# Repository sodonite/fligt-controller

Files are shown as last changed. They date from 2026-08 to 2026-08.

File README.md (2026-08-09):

Flight Controller
This is a custom flight controller engineered specifically for rocket stabilization and control. Powered by an STM32F722 microcontroller, it incorporates an ICM-45686 IMU alongside a BMP580 barometer, with an integrated microSD card slot dedicated to flight telemetry logging. The board supports 2S LiPo battery configurations featuring onboard charging functionality, as well as dedicated PWM output channels for servo actuation.

Designed in KiCad, the entire project is completely open source.

PCB:

3D Image:


Schematic:


Technical Specifications
Brain: STM32F722RET6 microcontroller.
IMU: ICM-45686 high-precision motion sensor.
Barometer: BMP580 altitude tracker.
Actuation: Multi-channel servo output via PWM.
Data Logging: Onboard MicroSD card slot.
Power Management:
BQ25883: 2-cell LiPo battery charger via USB-C.
TPS63070: 5V Buck-Boost regulator for servos.
LMR51430: 3.3V Buck regulator for the MCU and sensors.
D2: RGB LED (Common Anode) — Visual status indicator for system initialization, ready-to-fly state, and critical error reporting (IMU, battery, SD card, and power rails).

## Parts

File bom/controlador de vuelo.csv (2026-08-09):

Id | Identificador | Huella | Cantidad | Identificación | Suministrador y ref
1 | C1, C28, C29, C30 | C_0402_1005Metric | 4 | 1uF
2 | C2, C9, C12 | C_0603_1608Metric | 3 | 10uF
3 | C3, C5, C31 | C_0402_1005Metric | 3 | 10uF
4 | C4 | C_0201_0603Metric | 1 | 47nF
5 | C6 | C_0603_1608Metric | 1 | 44uF
6 | C7, C8 | C_0805_2012Metric | 2 | 10uF
7 | C10, C11, C13 | C_0805_2012Metric | 3 | 22uF
8 | C14, C15, C19, C20, C21, C22, C23, C24, C25, C26, C27, C37 | C_0201_0603Metric | 12 | 100nF
9 | C16 | C_0603_1608Metric | 1 | 2.2uF
10 | C17, C18 | C_0402_1005Metric | 2 | 22uF
11 | C32 | C_0201_0603Metric | 1 | 2.2uF
12 | C33, C34 | C_0201_0603Metric | 2 | 20pF
13 | C35, C36 | C_0201_0603Metric | 2 | 6.8pF
14 | Card1 | TF-SMD_TF-01A | 1 | TF-01A
15 | D1 | LED_0402_1005Metric | 1 | LED
16 | J1 | TerminalBlock_Xinya_XY308-2.54-2P_1x02_P2.54mm_Horizontal | 1 | Screw_Terminal_01x02
17 | J2, J3 | PinHeader_1x03_P2.54mm_Vertical | 2 | Conn_01x03
18 | L4 | L0603 | 1 | FCM1608KF-601T03
19 | L5 | L2520 | 1 | DFE252012F-1R0M=P2
20 | L6 | IND-SMD_L4.0-W4.0-A | 1 | XFL4020-152MEC
21 | L7 | IND-SMD_L3.0-W3.0 | 1 | YHNR3015-5R6M
22 | LED1 | LED-SMD_4P-L1.6-W1.5-TR-1 | 1 | SZYY1615RGB-B 4PIN
23 | R1, R2 | R_0201_0603Metric | 2 | 5.1k
24 | R3 | R_0201_0603Metric | 1 | 383
25 | R4 | R_0201_0603Metric | 1 | 5.23K
26 | R5 | R_0201_0603Metric | 1 | 30.1K
27 | R6, R7, R8, R9, R10, R11, R12, R13, R16, R17, R18, R19, R20, R21, R22 | R_0201_0603Metric | 15 | 10K
28 | R14 | R_0402_1005Metric | 1 | 100K
29 | R15 | R_0402_1005Metric | 1 | 22.1K
30 | R23 | R_0201_0603Metric | 1 | 330
31 | R24, R25 | R_0201_0603Metric | 2 | 220
32 | SW1, SW2 | SW-SMD_L3.9-W3.0-P4.45 | 2 | TS-1088-AR02016
33 | U1 | VFQFPN-24_L4.0-W4.0-P0.50-BL-EP2.8 | 1 | BQ25883RGER
34 | U3 | LQFP-64_10x10mm_P0.5mm | 1 | STM32F722RETx
35 | U5 | VQFN-HR-15_L3.0-W2.5-P0.50-BL_TPS63070RNMR | 1 | TPS63070RNMR
36 | U6 | SOT-23-6 | 1 | LMR51430
37 | U7 | LGA-14_L3.0-W2.5-P0.50-TL | 1 | ICM-45686
38 | U8 | LGA-10_L2.0-W2.0-P0.50-TL_BMP580 | 1 | BMP580
39 | USB1 | USB-C-SMD_TYPE-C-16PIN-2MD-073 | 1 | TYPE-C 16PIN 2MD
40 | X1 | CRYSTAL-SMD_4P-L3.2-W2.5-BL | 1 | X322525MOB4SI
41 | X2 | FC-135R_L3.2-W1.5 | 1 | Q13FC1350000400

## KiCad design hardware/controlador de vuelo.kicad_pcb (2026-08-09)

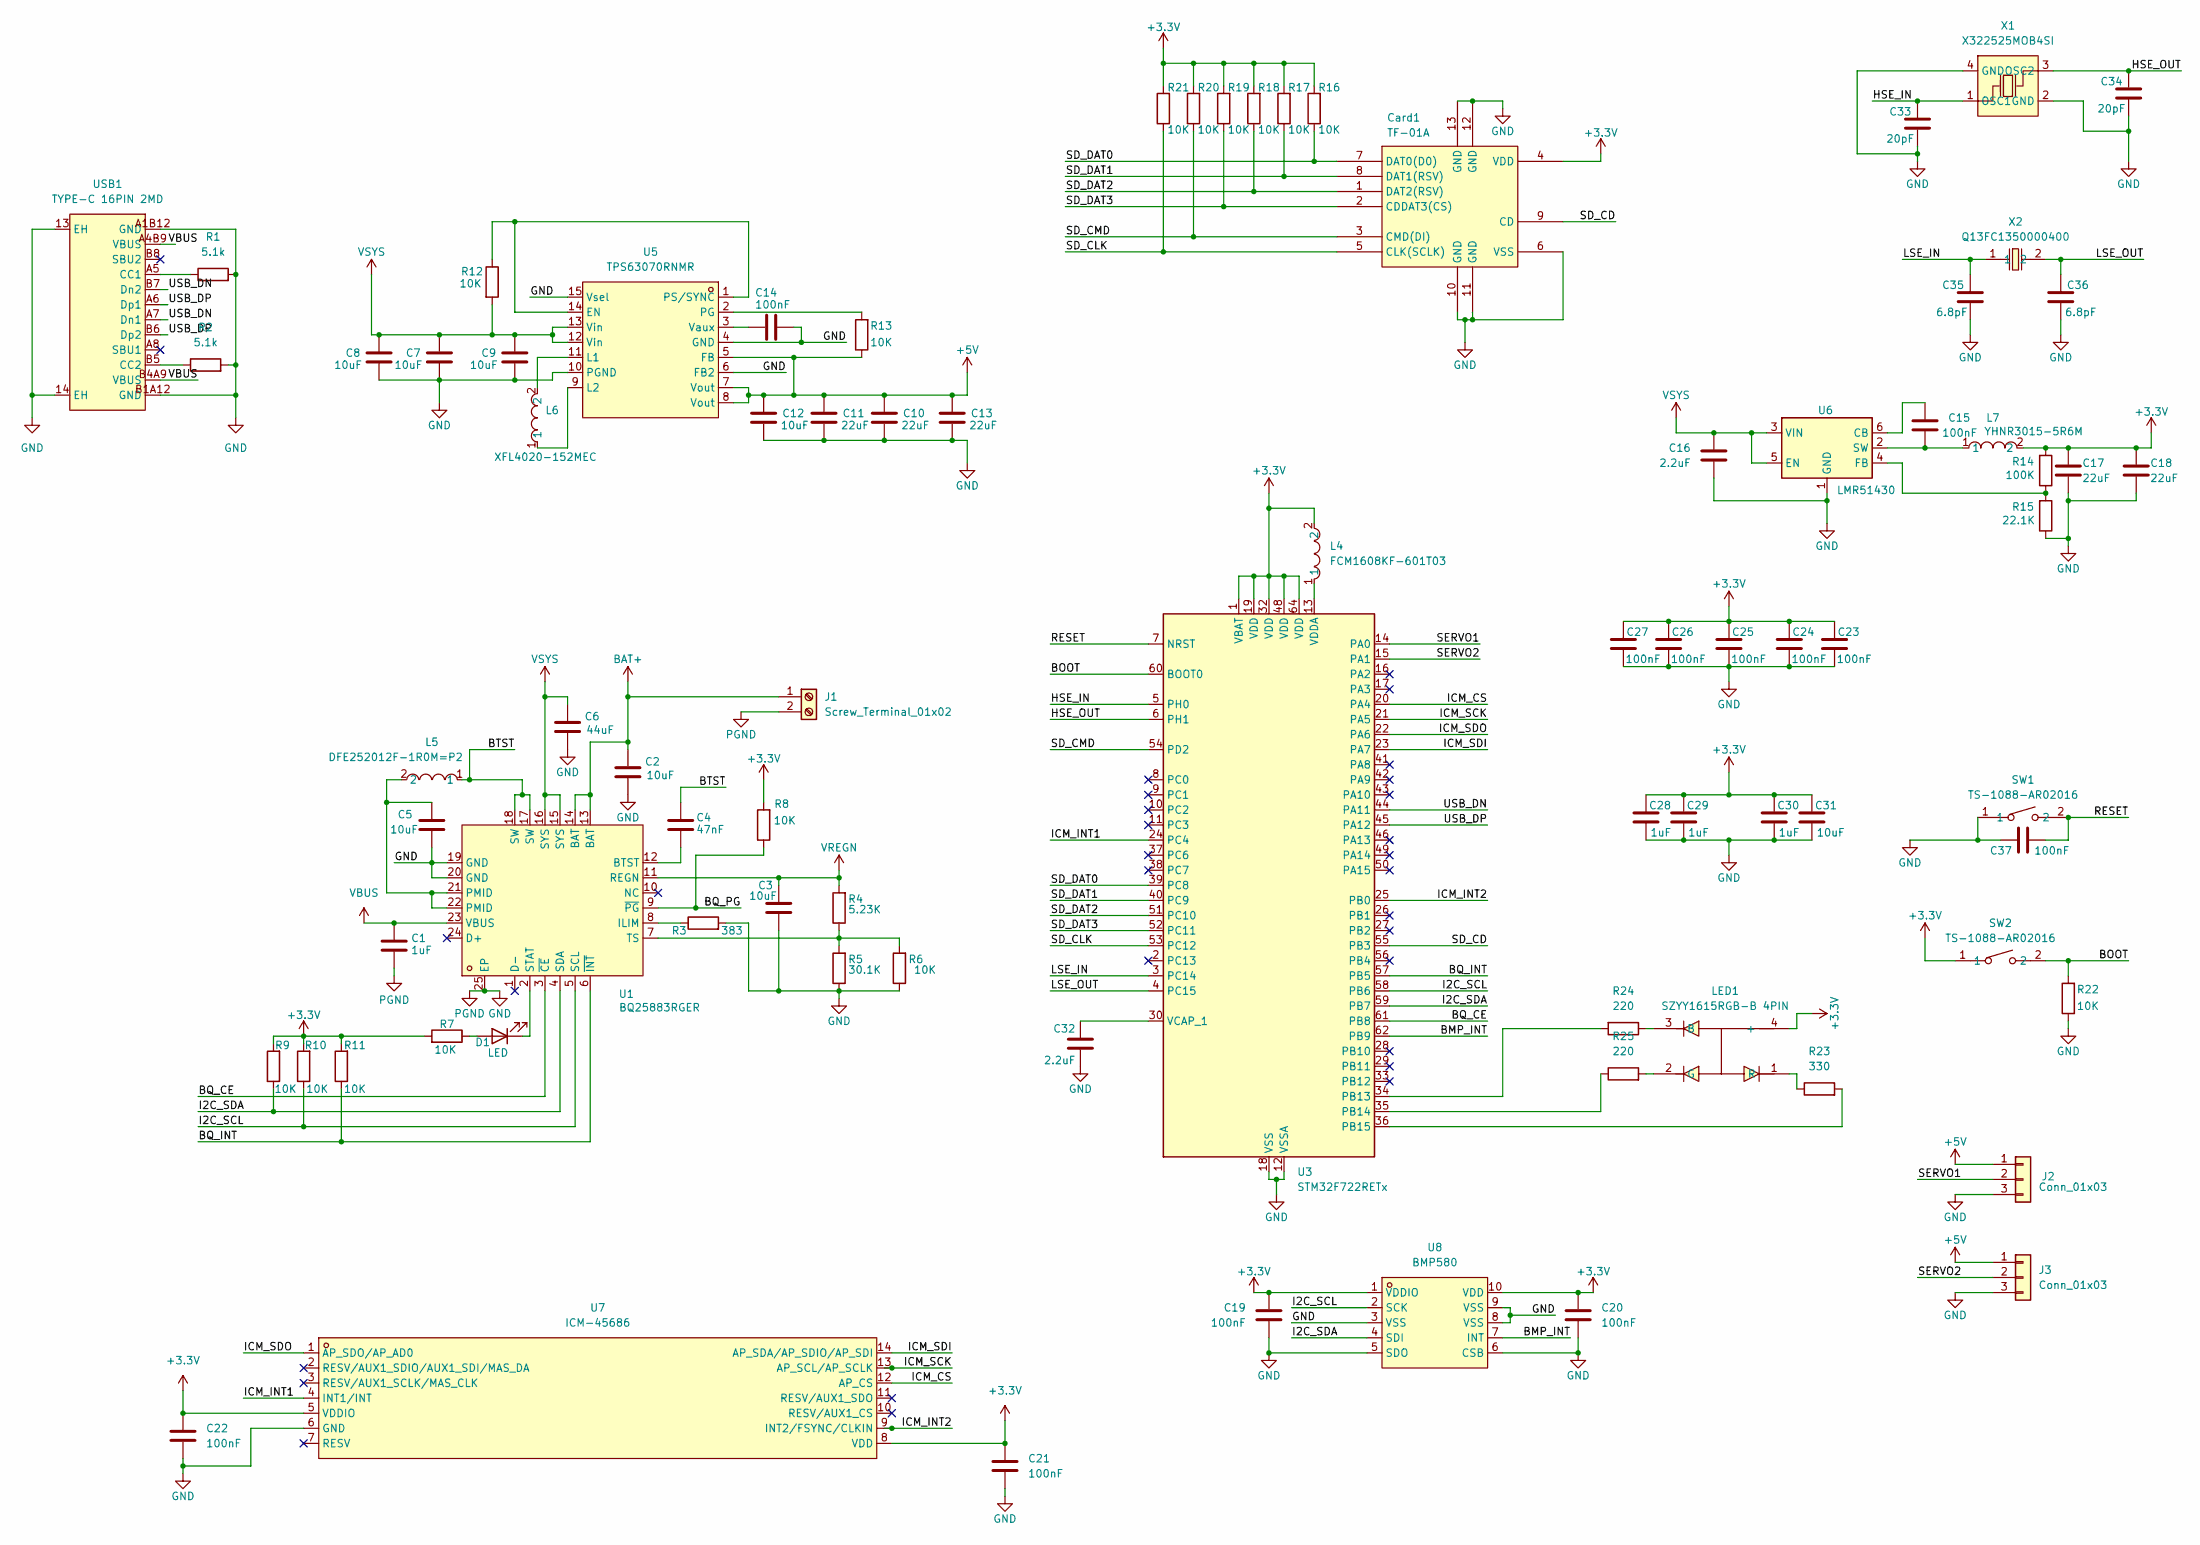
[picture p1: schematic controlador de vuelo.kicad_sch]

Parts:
C1, C28, C29, C30: 1uF; C_0402_1005Metric
C2, C9, C12: 10uF; C_0603_1608Metric
C3, C5, C31: 10uF; C_0402_1005Metric
C4: 47nF; C_0201_0603Metric
C6: 44uF; C_0603_1608Metric
C7, C8: 10uF; C_0805_2012Metric
C10, C11, C13: 22uF; C_0805_2012Metric
C14, C15, C19, C20, C21, C22, C23, C24, C25, C26, C27, C37: 100nF; C_0201_0603Metric
C16: 2.2uF; C_0603_1608Metric
C17, C18: 22uF; C_0402_1005Metric
C32: 2.2uF; C_0201_0603Metric
C33, C34: 20pF; C_0201_0603Metric
C35, C36: 6.8pF; C_0201_0603Metric
Card1: TF-01A; TF-SMD_TF-01A; LCSC Part C91145
D1: LED; LED_0402_1005Metric
J1: Screw_Terminal_01x02; TerminalBlock_Xinya_XY308-2.54-2P_1x02_P2.54mm_Horizontal
J2, J3: Conn_01x03; PinHeader_1x03_P2.54mm_Vertical
L4: FCM1608KF-601T03; L0603; LCSC Part C141723
L5: DFE252012F-1R0M=P2; L2520; LCSC Part C435392
L6: XFL4020-152MEC; IND-SMD_L4.0-W4.0-A; LCSC Part C3033018
L7: YHNR3015-5R6M; IND-SMD_L3.0-W3.0; LCSC Part C18236327
LED1: SZYY1615RGB-B 4PIN; LED-SMD_4P-L1.6-W1.5-TR-1; MPN SZYY1615RGB-B 4pin; LCSC Part C3029071
R1, R2: 5.1k; R_0201_0603Metric
R3: 383; R_0201_0603Metric
R4: 5.23K; R_0201_0603Metric
R5: 30.1K; R_0201_0603Metric
R6, R7, R8, R9, R10, R11, R12, R13, R16, R17, R18, R19, R20, R21, R22: 10K; R_0201_0603Metric
R14: 100K; R_0402_1005Metric
R15: 22.1K; R_0402_1005Metric
R23: 330; R_0201_0603Metric
R24, R25: 220; R_0201_0603Metric
SW1, SW2: TS-1088-AR02016; SW-SMD_L3.9-W3.0-P4.45; LCSC Part C720477
U1: BQ25883RGER; VFQFPN-24_L4.0-W4.0-P0.50-BL-EP2.8; LCSC Part C544362
U3: STM32F722RETx; LQFP-64_10x10mm_P0.5mm
U5: TPS63070RNMR; VQFN-HR-15_L3.0-W2.5-P0.50-BL_TPS63070RNMR; LCSC Part C109322
U6: LMR51430; SOT-23-6
U7: ICM-45686; LGA-14_L3.0-W2.5-P0.50-TL; LCSC Part C22459454
U8: BMP580; LGA-10_L2.0-W2.0-P0.50-TL_BMP580; LCSC Part C22391138
USB1: TYPE-C 16PIN 2MD; USB-C-SMD_TYPE-C-16PIN-2MD-073; MPN TYPE-C 16PIN 2MD(073); LCSC Part C2765186
X1: X322525MOB4SI; CRYSTAL-SMD_4P-L3.2-W2.5-BL; LCSC Part C9006
X2: Q13FC1350000400; FC-135R_L3.2-W1.5; LCSC Part C32346

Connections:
+3.3V: C17.1, C18.1, C19.1, C20.1, C21.1, C22.1, C23.1, C24.1, C25.1, C26.1, C27.1, C28.1, C29.1, C30.1, C31.1, Card1.4 (VDD), L4.2, L7.2, LED1.4 (+), R7.2, R8.2, R9.2, R10.2, R11.2, R14.2, R16.2, R17.2, R18.2, R19.2, R20.2, R21.2, SW2.1, U3.1 (VBAT), U3.19 (VDD), U3.32 (VDD), U3.48 (VDD), U3.64 (VDD), U7.5 (VDDIO), U7.8 (VDD), U8.1 (VDDIO), U8.10 (VDD)
+5V: C10.1, C11.1, C12.1, C13.1, J2.1, J3.1, R13.1, U5.5 (FB), U5.7 (Vout), U5.8 (Vout)
/BMP_INT: U3.62 (PB9), U8.7 (INT)
/BOOT: R22.2, SW2.2, U3.60 (BOOT0)
/BQ_CE: U1.3 (~CE), U3.61 (PB8)
/BQ_INT: R11.1, U1.6 (~INT), U3.57 (PB5)
/BQ_PG: R8.1, U1.9 (~PG)
/BTST: C4.1, L5.1, U1.17 (SW), U1.18 (SW)
/HSE_IN: C33.1, U3.5 (PH0), X1.1 (OSC1)
/HSE_OUT: C34.1, U3.6 (PH1), X1.3 (OSC2)
/I2C_SCL: R10.1, U1.5 (SCL), U3.58 (PB6), U8.2 (SCK)
/I2C_SDA: R9.1, U1.4 (SDA), U3.59 (PB7), U8.4 (SDI)
/ICM_CS: U3.20 (PA4), U7.12 (AP_CS)
/ICM_INT1: U3.24 (PC4), U7.4 (INT1/INT)
/ICM_INT2: U3.25 (PB0), U7.9 (INT2/FSYNC/CLKIN)
/ICM_SCK: U3.21 (PA5), U7.13 (AP_SCL/AP_SCLK)
/ICM_SDI: U3.23 (PA7), U7.14 (AP_SDA/AP_SDIO/AP_SDI)
/ICM_SDO: U3.22 (PA6), U7.1 (AP_SDO/AP_AD0)
/LSE_IN: C35.1, U3.3 (PC14), X2.1
/LSE_OUT: C36.1, U3.4 (PC15), X2.2
/RESET: C37.2, SW1.2, U3.7 (NRST)
/SD_CD: Card1.9 (CD), U3.55 (PB3)
/SD_CLK: Card1.5 (CLK(SCLK)), R21.1, U3.53 (PC12)
/SD_CMD: Card1.3 (CMD(DI)), R20.1, U3.54 (PD2)
/SD_DAT0: Card1.7 (DAT0(D0)), R16.1, U3.39 (PC8)
/SD_DAT1: Card1.8 (DAT1(RSV)), R17.1, U3.40 (PC9)
/SD_DAT2: Card1.1 (DAT2(RSV)), R18.1, U3.51 (PC10)
/SD_DAT3: Card1.2 (CDDAT3(CS)), R19.1, U3.52 (PC11)
/SERVO1: J2.2, U3.14 (PA0)
/SERVO2: J3.2, U3.15 (PA1)
/USB_DN: U3.44 (PA11), USB1.A7 (Dn1), USB1.B7 (Dn2)
/USB_DP: U3.45 (PA12), USB1.A6 (Dp1), USB1.B6 (Dp2)
BAT+: C2.1, J1.1, U1.13 (BAT), U1.14 (BAT)
GND: C1.2, C2.2, C3.2, C5.2, C6.2, C7.2, C8.2, C9.2, C10.2, C11.2, C12.2, C13.2, C14.2, C16.2, C17.2, C18.2, C19.2, C20.2, C21.2, C22.2, C23.2, C24.2, C25.2, C26.2, C27.2, C28.2, C29.2, C30.2, C31.2, C32.2, C33.2, C34.2, C35.2, C36.2, C37.1, Card1.6 (VSS), Card1.10 (GND), Card1.11 (GND), Card1.12 (GND), Card1.13 (GND), J1.2, J2.3, J3.3, R1.2, R2.2, R3.2, R5.1, R6.1, R15.1, R22.1, SW1.1, U1.19 (GND), U1.20 (GND), U1.25 (EP), U3.12 (VSSA), U3.18 (VSS), U3.31 (VSS), U3.47 (VSS), U3.63 (VSS), U5.4 (GND), U5.6 (FB2), U5.10 (PGND), U5.15 (Vsel), U6.1 (GND), U7.6 (GND), U8.3 (VSS), U8.5 (SDO), U8.6 (CSB), U8.8 (VSS), U8.9 (VSS), USB1.13 (EH), USB1.14 (EH), USB1.A1B12 (GND), USB1.B1A12 (GND), X1.2 (GND), X1.4 (GND)
unnamed: C5.1, L5.2, U1.21 (PMID), U1.22 (PMID)
unnamed: D1.2 (A), R7.1
unnamed: D1.1 (K), U1.2 (STAT)
unnamed: LED1.3 (B), R24.1
unnamed: LED1.2 (G), R25.2
unnamed: LED1.1 (R), R23.1
unnamed: C4.2, U1.12 (BTST)
unnamed: R3.1, U1.8 (ILIM)
unnamed: R4.1, R5.2, R6.2, U1.7 (TS)
unnamed: R24.2, U3.34 (PB13)
unnamed: R25.1, U3.35 (PB14)
unnamed: R23.2, U3.36 (PB15)
unnamed: C32.1, U3.30 (VCAP_1)
unnamed: L4.1, U3.13 (VDDA)
unnamed: R12.1, U5.1 (PS/SYNC), U5.14 (EN)
unnamed: L6.2, U5.11 (L1)
unnamed: L6.1, U5.9 (L2)
unnamed: R13.2, U5.2 (PG)
unnamed: C14.1, U5.3 (Vaux)
unnamed: C15.1, U6.6 (CB)
unnamed: R14.1, R15.2, U6.4 (FB)
unnamed: C15.2, L7.1, U6.2 (SW)
unnamed: R1.1, USB1.A5 (CC1)
unnamed: R2.1, USB1.B5 (CC2)
VBUS: C1.1, U1.23 (VBUS), USB1.A4B9 (VBUS), USB1.B4A9 (VBUS)
VREGN: C3.1, R4.2, U1.11 (REGN)
VSYS: C6.1, C7.1, C8.1, C9.1, C16.1, R12.2, U1.15 (SYS), U1.16 (SYS), U5.12 (Vin), U5.13 (Vin), U6.3 (VIN), U6.5 (EN)

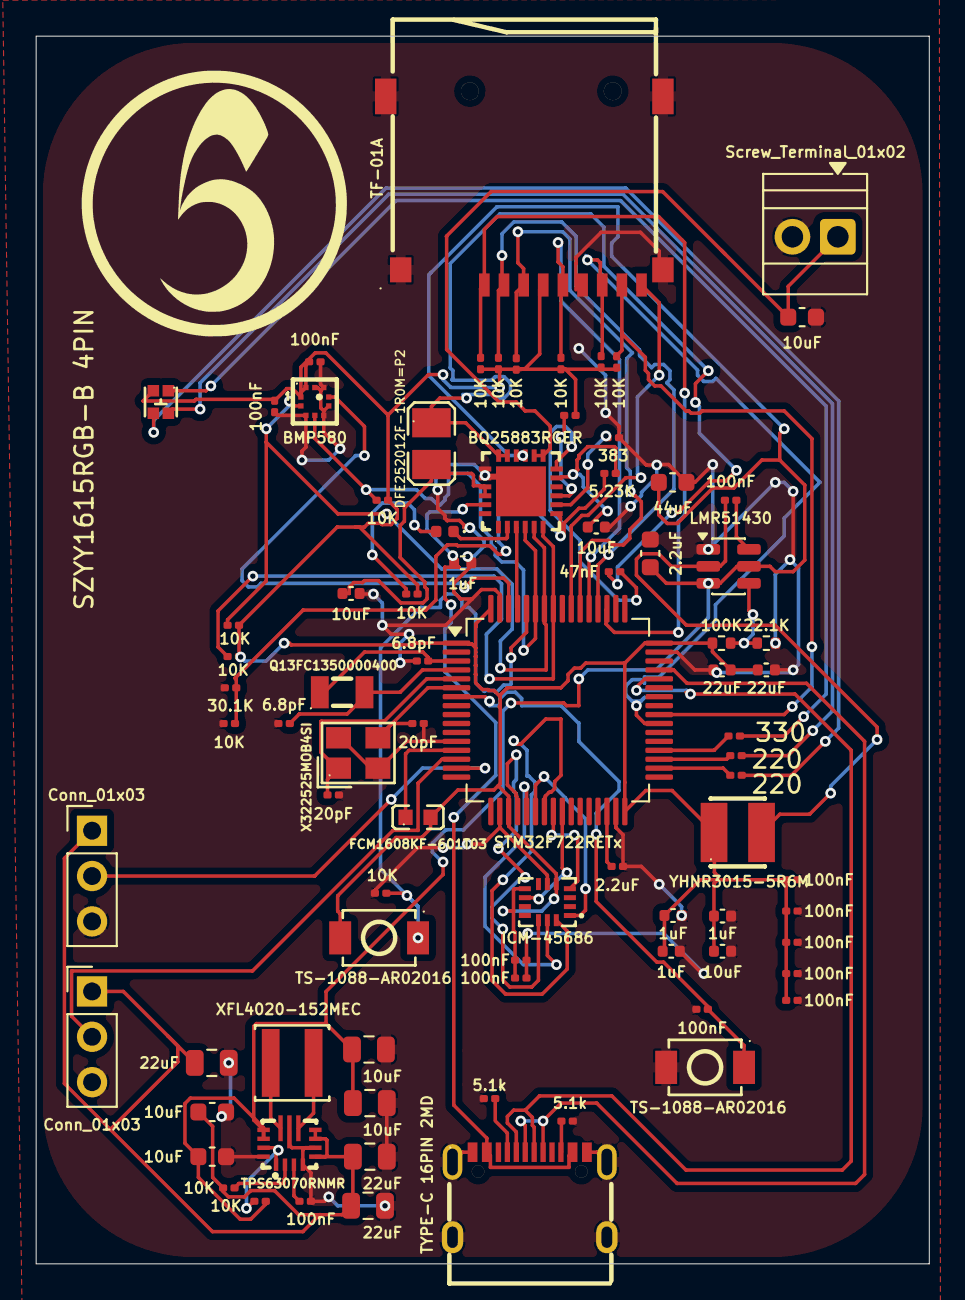
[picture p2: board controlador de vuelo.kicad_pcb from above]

Board: 2 copper layers, 50.0 x 68.7 mm, 83 parts (0 on the bottom side), 61 nets.

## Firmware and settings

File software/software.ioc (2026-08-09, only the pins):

Mcu.UserName=STM32F722RETx
PA0-WKUP.Signal=S_TIM2_CH1_ETR
PA1.Signal=S_TIM2_CH2
PA11.Signal=USB_OTG_FS_DM
PA12.Signal=USB_OTG_FS_DP
PA4.Signal=SPI1_NSS
PA5.Signal=SPI1_SCK
PA6.Signal=SPI1_MISO
PA7.Signal=SPI1_MOSI
PB0.Signal=GPXTI0
PB13.GPIO_Label=LED_B
PB13.Signal=GPIO_Output
PB14.GPIO_Label=LED_G 
PB14.Signal=GPIO_Output
PB15.GPIO_Label=LED_R
PB15.Signal=GPIO_Output
PB3.Signal=GPIO_Input
PB5.Signal=GPXTI5
PB6.Signal=I2C1_SCL
PB7.Signal=I2C1_SDA
PB8.Signal=GPIO_Output
PB9.Signal=GPXTI9
PC10.Signal=SDMMC1_D2
PC11.Signal=SDMMC1_D3
PC12.Signal=SDMMC1_CK
PC14-OSC32_IN.Signal=RCC_OSC32_IN
PC15-OSC32_OUT.Signal=RCC_OSC32_OUT
PC4.Signal=GPXTI4
PC8.Signal=SDMMC1_D0
PC9.Signal=SDMMC1_D1
PD2.Signal=SDMMC1_CMD
PH0-OSC_IN.Signal=RCC_OSC_IN
PH1-OSC_OUT.Signal=RCC_OSC_OUT
